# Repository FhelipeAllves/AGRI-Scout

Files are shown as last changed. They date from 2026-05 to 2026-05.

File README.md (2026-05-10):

# AGRI-Scout 🚜
**Autonomous Agricultural Inspection Robot**

AGRI-Scout est un robot agricole différentiel autonome à quatre roues motrices, conçu pour la navigation dans les rangées de cultures et l'analyse de sol in-situ. Il combine la vision par ordinateur, un LiDAR, et une sonde à vis motorisée pour récolter des données pédologiques en temps réel.

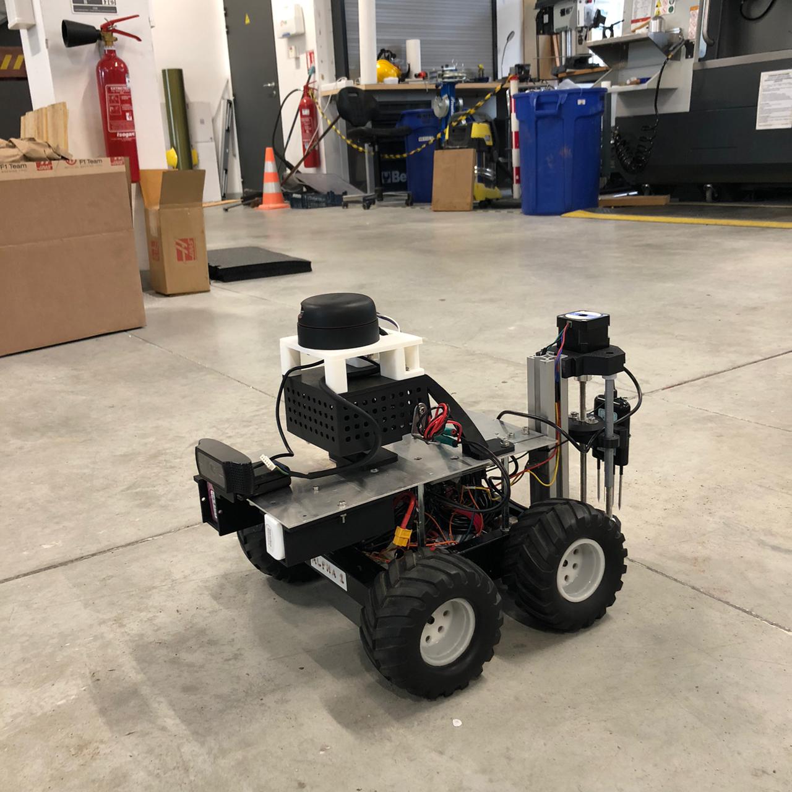
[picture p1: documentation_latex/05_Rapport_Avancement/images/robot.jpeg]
AGRI-Scout


🎥 **[Voir la démo vidéo sur YouTube](https://www.youtube.com/shorts/bMWXOjUjSsw)**

---

## 📑 Sommaire
1. [Caractéristiques Principales](#-caractéristiques-principales)
2. [Architecture Matérielle](#-architecture-matérielle)
3. [Architecture Logicielle](#-architecture-logicielle)
4. [Installation et Prérequis](#-installation-et-prérequis)
5. [Démarrage Rapide](#-démarrage-rapide)
6. [Documentation](#-documentation)
7. [Auteurs](#-auteurs)

---

## 🌟 Caractéristiques Principales

* **Navigation Autonome :** Suivi de ligne blanche au sol via vision par ordinateur (OpenCV) avec contrôleur PD.
* **Évitement d'Obstacles :** Surveillance périmétrique en temps réel grâce au RPLiDAR pour prévenir les collisions.
* **Analyse de Sol Automatisée :** Déploiement mécanique d'une sonde à vis motorisée par un moteur pas-à-pas NEMA 17.
* **Acquisition de Données :** Capteur industriel RS485 (Modbus RTU) mesurant 8 paramètres vitaux : NPK (Azote, Phosphore, Potassium), pH, Température, Humidité, Conductivité Électrique et Salinité.
* **Architecture Distribuée :** Prise de décision par Raspberry Pi 4 (ROS 2 Jazzy) et contrôle bas niveau temps réel par Arduino UNO avec un protocole de communication sécurisé (\textit{watchdog}).

---

## 🛠️ Architecture Matérielle

Le robot est structuré sur deux étages pour isoler physiquement l'électronique de puissance et l'électronique de traitement.

### Composants Clés
* **Calculateur Principal :** Raspberry Pi 4 Model B (4GB)
* **Contrôleur Moteur :** Arduino UNO R3
* **Actionneurs :** 
  * 4x Moteurs DC brushed (Traction, skid-steering)
  * 1x Moteur pas-à-pas NEMA 17 (Sonde)
* **Capteurs :**
  * RPLiDAR (USB)
  * Webcam USB (V4L2)
  * Capteur de sol NPK 8-en-1 (RS485 vers USB)
  * SparkFun OpenLog Artemis (UART)

### Système d'Alimentation
Afin d'éviter les chutes de tension (brown-outs) induites par les appels de courant des moteurs, le système dispose de 3 circuits indépendants :
1. **Batterie LiPo 5000 mAh (3S) :** Moteurs de traction et ESC.
2. **Batterie LiPo 2200 mAh (3S) :** Moteur de la sonde (via Pont en H L298N).
3. **Powerbank USB-C 5V :** Alimentation exclusive du Raspberry Pi.

---

## 💻 Architecture Logicielle

Le projet s'appuie sur le framework **ROS 2 Jazzy** sous Ubuntu 24.04 (ou 22.04 pour versions antérieures compatibles).

* `agri_line_follower.py` : Nœud central intégrant la machine à états finis (FOLLOWING / HARVESTING).
* `agri_demo_hunter.py` : Mode de démonstration pour traquer un objet coloré plutôt qu'une ligne.
* `ros2_teleop.py` : Contrôle manuel du robot via SSH.
* `main_firmware.ino` : Firmware Arduino avec protocole binaire protégé par XOR Checksum et Watchdog matériel.

---

## 🚀 Installation et Prérequis

### Prérequis Logiciels (Raspberry Pi)
* Ubuntu Server/Desktop 24.04
* ROS 2 Jazzy
* Python 3 avec `opencv-python`, `pyserial`, `numpy`

### Clonage et Compilation
```bash
# Cloner le dépôt
git clone https://github.com/VOTRE_UTILISATEUR/AGRI-Scout.git
cd AGRI-Scout/agri-scout-modif

# Sourcer l'environnement ROS 2
source /opt/ros/jazzy/setup.bash

# Compiler l'espace de travail
colcon build --packages-select <nom_des_packages>
```

---

## 🏁 Démarrage Rapide

Pour les instructions détaillées, veuillez consulter le manuel utilisateur (User Manual) dans le dossier de documentation.

1. **Mise sous tension** : 
   - Branchez la Powerbank au Raspberry Pi.
   - Branchez la batterie LiPo 5000mAh et activez l'interrupteur principal.
   - Branchez la batterie LiPo 2200mAh.
2. **Connexion SSH** :
   ```bash
   ssh ubuntu@<IP_DU_RASPBERRY_PI>
   # Mot de passe par défaut : agribot
   ```
3. **Lancement de la Mission Autonome** :
   ```bash
   source /opt/ros/jazzy/setup.bash
   cd ~/AGRI-Scout_Modif
   source install/setup.bash
   ros2 launch ~/AGRI-Scout_Modif/demo.launch.py
   ```

---

## 📚 Documentation

L'intégralité de la documentation technique est disponible au format PDF compilé à partir des sources LaTeX dans `agri-scout-modif/documentation_latex/` :
- **01 Quick Start Guide** : Pour un démarrage immédiat.
- **02 User Manual** : Description détaillée de tous les modes d'utilisation.
- **03 Hardware Maintenance Manual** : Références des pièces, montage, impression 3D et débogage.
- **04 Developer Manual** : Architecture logicielle détaillée et protocole de communication.
- **05 Rapport d'Avancement** : Historique du projet, solutions explorées et perspectives.

---

## 👥 Auteurs

Ce projet a été réalisé par :
* **Pedro Alves**
* **Luiz Felipe**

*Projet réalisé dans le cadre de l'Unité d'Enseignement 3.4 / 4.4 à l'ENSTA Campus de Brest.*

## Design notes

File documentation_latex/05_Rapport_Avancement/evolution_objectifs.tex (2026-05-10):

\section{Objectifs Initiaux et Leur Évolution}

\subsection{Vision Initiale du Projet}

Au démarrage du projet, en septembre 2025, l'équipe avait défini un cahier des charges ambitieux. L'AGRI-Scout devait naviguer de façon autonome entre les rangées de cultures en utilisant la caméra pour suivre les lignes au sol, utiliser YOLO pour la détection et l'évaluation de la récolte (identifier l'état des cultures, détecter des végétaux, fruits ou signes de maladies), s'alimenter via un régulateur de tension centralisé (module Traco Power) depuis une unique batterie LiPo, et déployer une sonde de sol après chaque rangée pour cartographier les données NPK.

Les fonctionnalités de détection de feuilles, fruits, légumes et pestes via YOLO ont été retirées du périmètre du projet en raison des contraintes de temps, de la complexité d'annotation des données et des limitations de puissance de calcul. Ces fonctionnalités sont documentées comme pistes d'amélioration future à la section~\ref{sec:ameliorations}.

\subsection{Les Contraintes Rencontrées}

La confrontation avec la réalité matérielle du projet a révélé plusieurs obstacles imprévus qui ont nécessité des adaptations profondes de l'architecture initiale.

\subsubsection{Instabilité Électrique}

Sous forte charge logicielle, la carte Raspberry Pi 4 seule consomme environ 7W en pointe. Cependant, avec l'activation des périphériques USB (caméra, LiDAR, pont de communication), la consommation globale exigée au système d'alimentation peut facilement atteindre des pics de 12W à 15W.
 Le régulateur Traco Power, partagé avec les ESC des moteurs, ne pouvait pas absorber les pics de courant lors des accélérations, provoquant des chutes de tension et des redémarrages intempestifs (brown-outs) rendant toute mission autonome impossible.

\subsubsection{Problèmes de Communication Série}

Lors des premiers tests, le protocole de communication par caractères ASCII simples s'est avéré fragile : les perturbations électromagnétiques des moteurs corrompaient les trames, et l'accumulation de données dans le tampon série provoquait des blocages rendant le robot incontrôlable.

\subsubsection{Limites Computationnelles pour la Vision}

L'exécution de modèles YOLO sur la Raspberry Pi 4 n'atteignait que 2--3 images par seconde, insuffisant pour un contrôle réactif. Le projet a donc abandonné YOLO pour la phase de navigation, mais cette technologie reste pertinente pour de futures améliorations (voir section~\ref{sec:ameliorations}).

\subsection{Les Pivots Stratégiques}

Face à ces contraintes, l'équipe a procédé à une série d'adaptations qui ont transformé le prototype initial en un système fonctionnel et fiable.

\begin{table}[H]
\centering
\caption{Récapitulatif de l'évolution des objectifs du projet AGRI-Scout.}
\label{tab:evolution}
\renewcommand{\arraystretch}{1.4}
\begin{tabularx}{\textwidth}{|>{\bfseries}p{3.5cm}|X|X|}
\hline
\rowcolor{headerblue!20}
\textbf{Domaine} & \textbf{Objectif Initial} & \textbf{Solution Finale Adoptée} \\
\hline
Alimentation & Régulateur Traco Power centralisé & Isolation galvanique : powerbank USB-C pour la RPi, LiPo principale pour la traction \\
\hline
\rowcolor{rowalt}
Vision (détection récolte) & YOLO pour détecter végétaux, fruits et pestes & Retiré du périmètre ; segmentation HSV colorimétrique pour marqueurs de récolte \\
\hline
Navigation & Planification de trajectoire globale (Nav2) & Navigation réactive par contrôleur PD sur erreur de centrage \\
\hline
\rowcolor{rowalt}
Protocole Série & Trames ASCII simples & Paquets binaires 5 octets avec octet de début/fin et checksum XOR \\
\hline
Architecture logicielle & Scripts Python directs & ROS 2 Jazzy avec noeuds asynchrones et topics dédiés \\
\hline
\end{tabularx}
\end{table}

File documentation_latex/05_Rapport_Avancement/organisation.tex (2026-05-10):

\section{Organisation du Projet}

\subsection{Répartition des Tâches}

Pedro s'est chargé de la partie logicielle : déploiement de ROS 2 Jazzy sur la Raspberry Pi, développement du protocole de communication série sécurisé, calibration de la caméra et des paramètres HSV, et scripts utilitaires (télé-opération, pont série, monitoring). Luiz Felipe a pris en charge la conception physique du robot : modélisation et impression 3D du mécanisme de sondage, des bacs de batteries, de la tourelle LiDAR et des supports de capteurs, ainsi que le câblage électronique complet et le débogage des ESC. Durant la phase finale, les deux membres ont collaboré au développement du noeud principal \texttt{agri\_line\_follower}, aux tests d'intégration en laboratoire, à la campagne de validation terrain et au débogage des problèmes de communication ROS 2.

% ------------------------------------------------------------------ %
%  PHOTOS DU ROBOT - À INSÉRER (décommenter \includegraphics)
% ------------------------------------------------------------------ %
\begin{figure}[H]
    \centering
    
    \caption{Prototype AGRI-Scout finalisé : tourelle LiDAR, mécanisme de sondage et alimentation isolée.}
    \label{fig:robot_final}
\end{figure}

\begin{figure}[H]
    \centering
    \begin{minipage}{0.48\textwidth}
        \centering
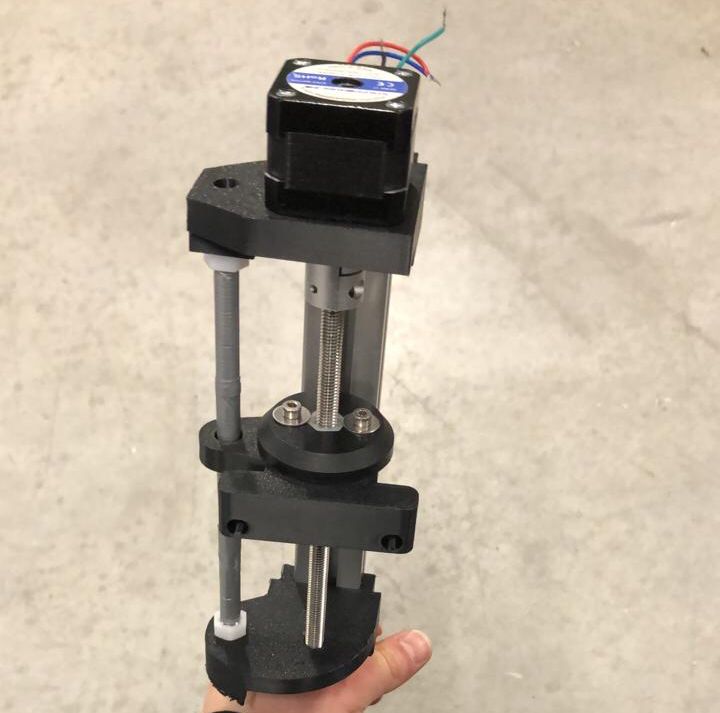
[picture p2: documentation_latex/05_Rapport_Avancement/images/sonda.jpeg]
        
    \end{minipage}
    \hfill
    \begin{minipage}{0.48\textwidth}
        \centering
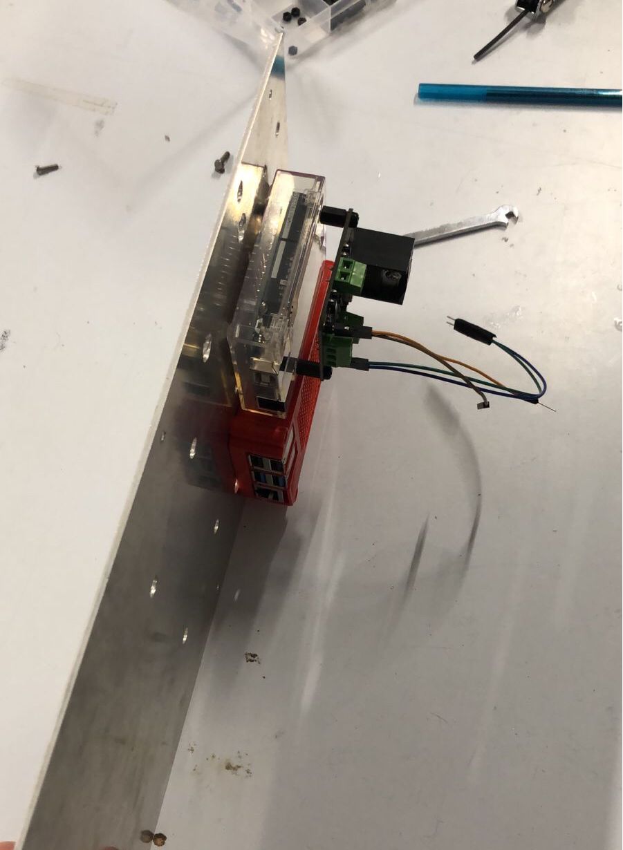
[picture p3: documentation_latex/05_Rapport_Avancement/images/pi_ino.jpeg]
        
    \end{minipage}
    \caption{Gauche : mécanisme de perforation 3D. Droite : architecture électronique avec isolation galvanique.}
    \label{fig:details_robot}
\end{figure}

\subsection{Chronologie du Projet (Septembre 2025 -- Avril 2026)}

Le tableau suivant retrace, mois par mois, les activités qui avaient été planifiées au démarrage du projet.

\renewcommand{\arraystretch}{1.5}
\begin{longtable}{|p{2.8cm}|p{11cm}|}
\hline
\rowcolor{headerblue!20}
\textbf{Mois} & \textbf{Activités Planifiées} \\
\hline
\endfirsthead
\hline
\rowcolor{headerblue!20}
\textbf{Mois} & \textbf{Activités Planifiées} \\
\hline
\endhead
\hline
\multicolumn{2}{r}{\textit{Suite sur la page suivante\ldots}}\\
\endfoot
\hline
\endlastfoot

\textbf{Septembre 2025}
& Définition du cahier des charges, formation de l'équipe, choix de la plateforme matérielle de base. Premiers contacts avec les composants (Arduino, ESC, LiPo). \\
\hline

\rowcolor{rowalt}
\textbf{Octobre 2025}
& Recherche bibliographique et état de l'art. Étude de l'architecture Master-Slave (RPi/Arduino). Premiers tests Arduino (PWM, lecture ultrasons). \\
\hline

\textbf{Novembre 2025}
& Assemblage mécanique préliminaire du châssis. Tests d'alimentation et dimensionnement énergétique. Premiers tests de vision (YOLO sur PC). \\
\hline

\rowcolor{rowalt}
\textbf{Décembre 2025}
& Rédaction du rapport partiel. Validation de la locomotion de base. Identification des problèmes d'alimentation (brown-outs Traco Power). Congés. \\
\hline

\textbf{Janvier 2026}
& Refonte de l'architecture d'alimentation (isolation galvanique). Migration vers USB série. Début de la conception 3D du mécanisme de sondage. Déploiement de ROS 2 Jazzy sur RPi. \\
\hline

\rowcolor{rowalt}
\textbf{Février 2026}
& Développement du noeud ROS 2 \texttt{agri\_line\_follower}. Conception du protocole de communication sécurisé. Impression 3D et assemblage des pièces mécaniques (tourelle LiDAR, bacs batteries). \\
\hline

\textbf{Mars 2026}
& Intégration du LiDAR RPLIDAR. Développement du watchdog logiciel. Tests d'intégration en conditions contrôlées. Calibration de la caméra. Débogage des ESC (frein ABS RC). \\
\hline

\rowcolor{rowalt}
\textbf{Avril 2026}
& Campagne de tests terrain. Validation de la mission autonome complète (suivi de ligne + sondage). Rédaction du rapport final d'avancement. \\
\hline

\end{longtable}

\subsubsection*{Problèmes ayant impacté le planning}

Plusieurs difficultés imprévues ont provoqué des décalages par rapport au planning initial. Le problème d'alimentation a été identifié tardivement et a nécessité une refonte complète de l'architecture électrique, aboutissant à trois sources isolées : une powerbank USB-C pour la Raspberry Pi, une batterie LiPo principale pour la traction, et une seconde batterie LiPo moins puissante dédiée au mécanisme de montée/descente de la sonde. Cette refonte a retardé le démarrage des développements logiciels de plusieurs semaines. La synchronisation entre Python/ROS 2 et le firmware Arduino a également demandé un travail itératif intense. Enfin, une pénurie de filament dans les imprimantes 3D du laboratoire a retardé la fabrication des pièces mécaniques, repoussant les tests finaux et la campagne de validation terrain.

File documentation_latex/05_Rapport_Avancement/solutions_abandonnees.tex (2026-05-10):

\section{Solutions Explorées et Abandonnées}

Cette section documente brièvement les pistes techniques explorées mais finalement écartées. Elle sert de guide aux futurs développeurs pour éviter de répéter les mêmes essais infructueux.

\subsection{Régulateur de Tension Centralisé (Traco Power)}
Le plan initial prévoyait un unique module Traco Power pour alimenter tout le système à partir d'une seule batterie LiPo. En pratique, les pics de courant des moteurs lors des accélérations provoquaient des chutes de tension sur le rail partagé, causant des redémarrages intempestifs de la Raspberry Pi (brown-outs). La solution retenue a été d'isoler électriquement les domaines d'alimentation : la Raspberry Pi est alimentée par une powerbank USB-C indépendante, le système de traction par une batterie LiPo principale, et le mécanisme de montée/descente de la sonde par une seconde batterie LiPo moins puissante, dédiée uniquement à cet actionneur.

\subsection{Vision YOLO pour la Navigation}
L'exécution de modèles YOLO sur la Raspberry Pi 4 n'atteignait que 2--3 images par seconde, insuffisant pour un contrôle réactif. La vision haute résolution a donc été remplacée par une segmentation colorimétrique HSV à 160x120 pixels avec saut de trames, atteignant 10--15 images par seconde. YOLO reste pertinent pour la détection de végétaux et de pestes, mais nécessite un matériel plus puissant (voir section~\ref{sec:ameliorations}).

\subsection{micro-ROS sur Arduino}
La bibliothèque micro-ROS aurait permis d'intégrer l'Arduino directement dans le graphe de communication ROS 2. Cependant, les ressources limitées de l'Arduino Uno (2~Ko de RAM, 32~Ko de Flash) causaient des instabilités mémoire lors de l'exécution simultanée de la sécurité ultrasonique et du client micro-ROS. L'équipe a préféré maintenir un protocole propriétaire léger sur l'Arduino, la logique ROS 2 restant entièrement côté Raspberry Pi.

% \subsection{IMU BNO055}
% L'IMU BNO055 avait été envisagée pour corriger les dérives de trajectoire dues au glissement (skid-steering). En pratique, le champ magnétique des moteurs perturbait la boussole interne, rendant les données de cap peu fiables. L'odométrie visuelle par centroïde de ligne, couplée au LiDAR, a suffi pour les missions de suivi de rang.

\subsection{Navigation Globale avec Nav2}
La stack Nav2 de ROS 2, qui inclut des planificateurs de trajectoire de type A*, a été étudiée. Son intégration exige une carte de l'environnement (via SLAM) et un système de localisation robuste, deux éléments non disponibles dans le périmètre du projet. Le contrôleur PD réactif, bien que plus simple, a été suffisant pour les missions en rang droit.

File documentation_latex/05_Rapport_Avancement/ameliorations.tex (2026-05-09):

\section{Pistes d'Amélioration et Perspectives Futures}
\label{sec:ameliorations}

Cette section s'adresse aux futurs développeurs du projet AGRI-Scout. Les axes proposés sont classés par ordre croissant de difficulté et de complexité. Le choix du matériel et des bibliothèques devra être adapté au budget et aux équipements disponibles à l'ENSTA au moment de la reprise du projet.

% ----------------------------------------------------------
\subsection{Axe 1 : Refonte Mécanique et Châssis}

Le point de départ le plus accessible pour les prochains groupes est une intervention purement mécanique, sans modifier le logiciel existant. Le châssis de base actuel est un châssis RC générique dont les moteurs posent des problèmes récurrents de décalibration : la symétrie de puissance entre les roues gauche et droite se dégrade au fil du temps, rendant le suivi de ligne de moins en moins précis.

L'objectif de cet axe serait de remodeler le châssis de base et l'ensemble du système de roues pour obtenir un robot visuellement plus propre, mieux organisé et plus fiable mécaniquement. Un système de propulsion plus tolérant aux défaillances — par exemple des moteurs à encodeurs qui permettent un retour de position réel — résoudrait directement le problème de décalibration. Cette refonte permettrait aux étudiants de travailler sur différentes pièces mécaniques et matériaux, de concevoir et imprimer de nouvelles pièces en 3D, et, une fois la mécanique stabilisée, de garantir un fonctionnement optimal des algorithmes de navigation déjà existants sans toucher au code.

\noindent Compétences développées : CAO (Autodesk Inventor / Fusion 360), impression 3D, intégration mécanique-électronique, caractérisation de moteurs DC.

\noindent Ressources utiles :
\begin{itemize}
    \item Encodeurs et moteurs DC à encodeur (exemple : Pololu) : \url{https://www.pololu.com/category/12/motors-solenoids-driver-boards}
    \item Modeles 3D pour la robotique : \url{https://grabcad.com/library?categories=robotics}
    \item Comparatif châssis robotiques : \href{https://www.fdatabot.com/top-10-mobile-robot-chassis-compared-types-features-selection-guide/}{Lien vers fdatabot.com}
\end{itemize}

% ----------------------------------------------------------
\subsection{Axe 2 : Upgrade Matériel et Navigation Avancée}

La principale limitation de l'architecture actuelle est la puissance de calcul de la Raspberry Pi 4, insuffisante pour des algorithmes de vision ou de planification complexes. Remplacer l'ordinateur de bord par une plateforme plus puissante, comme une NVIDIA Jetson ou un Arduino UNO Q 4GB (carte Arduino intégrant processeur et capacités d'IA dans un module compact, alternative économique à environ 60~€), permettrait d'envisager l'intégration de Nav2 \cite{ros2_nav2} avec un algorithme A* pour la navigation autonome en champ.

\noindent Ressources utiles :
\begin{itemize}
    \item NVIDIA Jetson --- portail développeur : \url{https://developer.nvidia.com/embedded/develop/hardware}
    \item Arduino UNO Q --- page officielle Arduino : \url{https://www.arduino.cc/product-uno-q}
    \item Navigation 2 (Nav2) --- documentation ROS 2 : \url{https://docs.nav2.org/index.html}
    \item Algorithme A* expliqué visuellement : \url{https://www.redblobgames.com/pathfinding/a-star/introduction.html}
\end{itemize}

% ----------------------------------------------------------
\subsection{Axe 3 : Détection de Végétation et de Pestes par YOLO}

Cet axe reprend l'objectif initial du projet, retiré du périmètre par contrainte de temps et de calcul : utiliser un modèle YOLO entraîné sur des images agricoles pour identifier l'état des cultures (plantes malades, stress hydrique, infestations), détecter des fruits mûrs ou légumes prêts à la récolte, et classifier le type de culture pour adapter les seuils d'analyse NPK. Des bases de données annotées existent librement en ligne pour entraîner ou affiner le modèle.

\noindent Ressources utiles :
\begin{itemize}
    \item Documentation officielle Ultralytics YOLO : \url{https://docs.ultralytics.com/}
    \item Dataset PlantVillage (maladies de plantes) : \url{https://www.kaggle.com/datasets/emmarex/plantdisease}
    \item Datasets agricoles annotés (Roboflow Universe) : \url{https://universe.roboflow.com/search?q=pest+detection+agriculture}
    \item Tutoriel entraînement YOLO sur dataset personnalisé : \url{https://docs.ultralytics.com/modes/train/}
\end{itemize}

% ----------------------------------------------------------
\subsection{Axe 4 : Navigation GPS RTK et Missions par Points de Passage}

L'intégration d'un récepteur GPS RTK représente l'axe le plus ambitieux et le plus complexe techniquement, mais aussi le plus coûteux en termes d'équipement. Un GPS RTK permettrait une localisation absolue de précision décimétrique à centimétrique, ouvrant la voie à des missions géoréférencées par waypoints : l'opérateur définirait à l'avance les positions d'échantillonnage sur une carte et le robot naviguerait automatiquement entre ces points, générant une carte de fertilité géoréférencée de la parcelle.

La principale contrainte de cet axe est le coût du matériel : un récepteur GPS RTK de qualité professionnelle représente un investissement significatif qui dépasse généralement le budget d'un projet étudiant. Cependant, une précision de l'ordre du mètre (voire inférieure) serait déjà suffisante pour réaliser des missions agricoles intéressantes et des études approfondies. La faisabilité de cet axe dépendra donc directement de la disponibilité d'un équipement compatible au sein de l'ENSTA ou d'un prêt institutionnel.

Sur le plan logiciel, un filtre de Kalman étendu, disponible via le package ROS 2 \texttt{robot\_localization}, permettrait de fusionner les données GPS, IMU et odométrie pour une localisation robuste en conditions réelles.

\noindent Ressources utiles :
\begin{itemize}
    \item Package ROS 2 \texttt{robot\_localization} (EKF) : \url{https://docs.ros.org/en/noetic/api/robot_localization/html/index.html}
    \item Introduction au filtre de Kalman --- tutoriel visuel : \url{https://www.bzarg.com/p/how-a-kalman-filter-works-in-pictures/}
    \item Guide GPS RTK open-source (ZED-F9P, $\sim$200~€) : \url{https://learn.sparkfun.com/tutorials/gps-rtk2-hookup-guide}
\end{itemize}

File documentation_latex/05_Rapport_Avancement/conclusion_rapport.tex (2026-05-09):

\section{Conclusion}

Le projet AGRI-Scout aura été, avant tout, une leçon sur la distance qui sépare la conception théorique de la réalité du déploiement matériel. Les obstacles rencontrés (instabilité électrique, synchronisation Python/Arduino, contraintes d'impression 3D, limitations de calcul pour la vision) ont conduit l'équipe à repenser ses choix de façon itérative, aboutissant souvent à des solutions plus simples mais plus robustes que celles envisagées initialement. Le prototype final remplit ses objectifs fondamentaux : navigation autonome par suivi de ligne, détection d'obstacles par LiDAR, mécanisme de sondage du sol conçu et fabriqué en 3D, et collecte automatisée de données multiparamétriques via la sonde industrielle RS485.

Ce projet a permis à l'équipe d'acquérir une expérience pratique dans des domaines rarement enseignés en cours magistral : gestion des conflits électroniques en système embarqué, conception mécanique itérative, débogage de systèmes distribués en temps réel. La valeur de ce travail ne réside pas uniquement dans le robot livré, mais aussi dans la documentation des impasses techniques. Savoir ce qui n'a pas fonctionné est essentiel. Les solutions abandonnées et les pivots stratégiques constituent, pour les futurs développeurs, un guide pour éviter de répéter les mêmes erreurs et accélérer la prise en main du système.

L'AGRI-Scout est un prototype qui peut encore progresser. La réintégration de la détection YOLO pour la reconnaissance des végétaux et des pestes, la navigation par waypoints GPS RTK, et l'utilisation d'une plateforme de calcul plus puissante sont des pistes concrètes pour les prochaines équipes qui reprendront ce projet.

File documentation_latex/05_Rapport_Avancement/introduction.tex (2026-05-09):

\section{Introduction}

\subsection{Contexte et Motivation}

Face à la croissance démographique mondiale et à la nécessité de préserver les ressources environnementales, l'agriculture moderne opère une transition vers l'agriculture de précision. Cette approche vise à optimiser les rendements tout en minimisant l'usage d'intrants grâce à une gestion différenciée des parcelles \cite{precision_ag_review}.

La qualité du sol est un facteur déterminant pour la santé des cultures. Traditionnellement, son analyse nécessite un échantillonnage manuel fastidieux et des analyses en laboratoire coûteuses, ce qui limite la fréquence des données disponibles pour l'agriculteur \cite{soil_sensing_review}. L'automatisation de ce processus par la robotique mobile constitue une solution pour permettre un suivi temporel et spatial plus régulier \cite{agri_robotics}.

\subsection{Présentation du Projet AGRI-Scout}

Le projet AGRI-Scout vise à concevoir et prototyper un robot mobile autonome capable de naviguer dans des rangées de cultures et d'effectuer des inspections in-situ. Le système intègre une plateforme de locomotion différentielle (skid-steering) pilotée par des ESC et supervisée par un Arduino Uno, une Raspberry Pi 4 exécutant ROS 2 Jazzy pour la navigation par vision et l'intégration LiDAR, et une sonde multiparamétrique 8-en-1 (NPK, pH, humidité, température, conductivité électrique) déployée via un mécanisme de perforation conçu et imprimé en 3D.

\subsection{Périmètre de ce Rapport}

Ce rapport d'avancement final n'est pas un document technique architectural. Son objectif est de retracer l'évolution du projet depuis ses ambitions initiales jusqu'à la version livrée : les adaptations imposées par les contraintes du terrain, l'organisation de l'équipe, les solutions explorées qui n'ont pas été retenues, et les pistes d'amélioration pour les futurs développeurs.

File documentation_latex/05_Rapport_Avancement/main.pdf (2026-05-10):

# (UE 4.4 - Projet)

### Agri-Scout : Robot Autonome pour l’Inspection Agricole et l’Analyse des Sols

# Rapport d’avancement interne

ENSTA Campus de Brest
2 Rue François Verny
29200 Brest Cedex 9, France Pedro ALVES DE ARAUJO SILVA pedro.alves@ensta.fr
Luiz Felipe BARROS ALVES
luiz.barros@ensta.fr

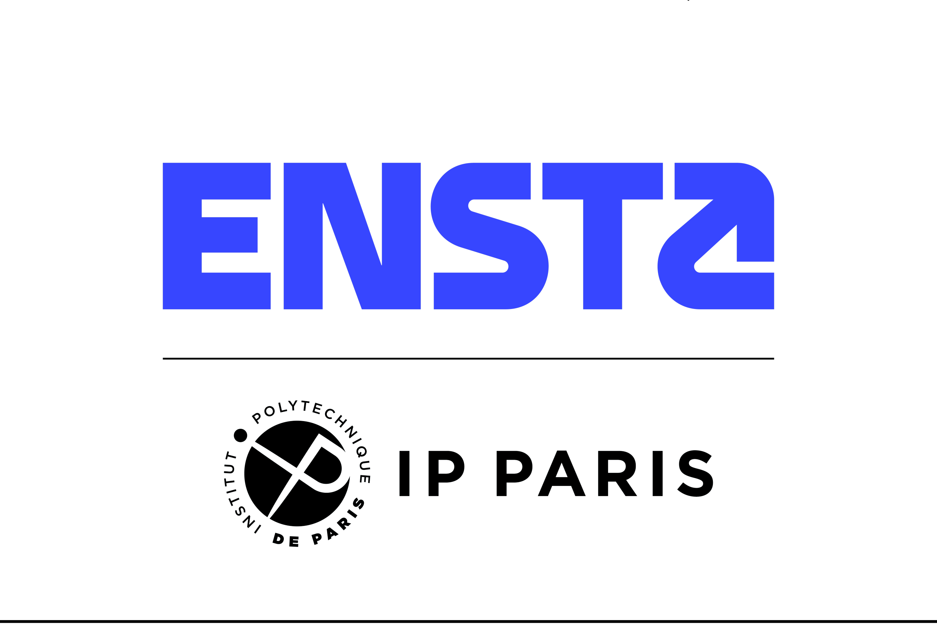
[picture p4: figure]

## Sommaire

1 Introduction | 1
2 Objectifs Initiaux et Leur Évolution | 1
3 Organisation du Projet | 3
4 Solutions Explorées et Abandonnées | 6

5 Pistes d’Amélioration et Perspectives Futures | 7
5.4 Axe 4 : Navigation GPS RTK et Missions par Points de Passage . . . | 8
6 Conclusion | 9

UE 4.4 - Projet | 1

## 1 Introduction

### 1.1 Contexte et Motivation

Face à la croissance démographique mondiale et à la nécessité de préserver les ressources environnementales, l’agriculture moderne opère une transition vers l’agriculture de précision. Cette approche vise à optimiser les rendements tout en minimisant l’usage d’intrants grâce à une gestion différenciée des parcelles [1].
La qualité du sol est un facteur déterminant pour la santé des cultures. Traditionnellement, son analyse nécessite un échantillonnage manuel fastidieux et des analyses en laboratoire coûteuses, ce qui limite la fréquence des données disponibles pour l’agriculteur [2]. L’automatisation de ce processus par la robotique mobile constitue une solution pour permettre un suivi temporel et spatial plus régulier [3].

### 1.2 Présentation du Projet AGRI-Scout

Le projet AGRI-Scout vise à concevoir et prototyper un robot mobile autonome capable de naviguer dans des rangées de cultures et d’effectuer des inspections insitu. Le système intègre une plateforme de locomotion différentielle (skid-steering) pilotée par des ESC et supervisée par un Arduino Uno, une Raspberry Pi 4 exécutant ROS 2 Jazzy pour la navigation par vision et l’intégration LiDAR, et une sonde multiparamétrique 8-en-1 (NPK, pH, humidité, température, conductivité électrique) déployée via un mécanisme de perforation conçu et imprimé en 3D.

### 1.3 Périmètre de ce Rapport

Ce rapport d’avancement final n’est pas un document technique architectural. Son objectif est de retracer l’évolution du projet depuis ses ambitions initiales jusqu’à la version livrée : les adaptations imposées par les contraintes du terrain, l’organisation de l’équipe, les solutions explorées qui n’ont pas été retenues, et les pistes d’amélioration pour les futurs développeurs.

## 2 Objectifs Initiaux et Leur Évolution

### 2.1 Vision Initiale du Projet

Au démarrage du projet, en septembre 2025, l’équipe avait défini un cahier des charges ambitieux. L’AGRI-Scout devait naviguer de façon autonome entre les rangées de cultures en utilisant la caméra pour suivre les lignes au sol, utiliser YOLO pour la détection et l’évaluation de la récolte (identifier l’état des cultures, détecter des végétaux, fruits ou signes de maladies), s’alimenter via un régulateur de tension centralisé (module Traco Power) depuis une unique batterie LiPo, et déployer une sonde de sol après chaque rangée pour cartographier les données NPK.
Les fonctionnalités de détection de feuilles, fruits, légumes et pestes via YOLO ont été retirées du périmètre du projet en raison des contraintes de temps, de la complexité d’annotation des données et des limitations de puissance de calcul. Ces fonctionnalités sont documentées comme pistes d’amélioration future à la section 5.

### 2.2 Les Contraintes Rencontrées

La confrontation avec la réalité matérielle du projet a révélé plusieurs obstacles imprévus qui ont nécessité des adaptations profondes de l’architecture initiale.

### 2.2.1 Instabilité Électrique

Sous forte charge logicielle, la carte Raspberry Pi 4 seule consomme environ 7W en pointe. Cependant, avec l’activation des périphériques USB (caméra, LiDAR, pont de communication), la consommation globale exigée au système d’alimentation peut facilement atteindre des pics de 12W à 15W. Le régulateur Traco Power, partagé avec les ESC des moteurs, ne pouvait pas absorber les pics de courant lors des accélérations, provoquant des chutes de tension et des redémarrages intempestifs (brown-outs) rendant toute mission autonome impossible.

### 2.2.2 Problèmes de Communication Série

Lors des premiers tests, le protocole de communication par caractères ASCII simples s’est avéré fragile : les perturbations électromagnétiques des moteurs corrompaient les trames, et l’accumulation de données dans le tampon série provoquait des blocages rendant le robot incontrôlable.

### 2.2.3 Limites Computationnelles pour la Vision

L’exécution de modèles YOLO sur la Raspberry Pi 4 n’atteignait que 2–3 images par seconde, insuffisant pour un contrôle réactif. Le projet a donc abandonné YOLO pour la phase de navigation, mais cette technologie reste pertinente pour de futures améliorations (voir section 5).

### 2.3 Les Pivots Stratégiques

Face à ces contraintes, l’équipe a procédé à une série d’adaptations qui ont transformé le prototype initial en un système fonctionnel et fiable.

Table 1 – Récapitulatif de l’évolution des objectifs du projet AGRI-Scout.

Domaine | Objectif Initial | Solution Finale Adoptée
Alimentation | Régulateur Traco Power centralisé | Isolation galvanique : power-bank USB-C pour la RPi, LiPo principale pour la trac-tion
Vision (détec-tion récolte) | YOLO pour détecter végé-taux, fruits et pestes | Retiré du périmètre ; seg-mentation HSV colorimé-trique pour marqueurs de ré-colte
Navigation | Planification de trajectoire globale (Nav2) | Navigation réactive par contrôleur PD sur erreur de centrage
Protocole Série | Trames ASCII simples | Paquets binaires 5 octets avec octet de début/fin et checksum XOR
Architecture lo-gicielle | Scripts Python directs | ROS 2 Jazzy avec noeuds asynchrones et topics dédiés

## 3 Organisation du Projet

### 3.1 Répartition des Tâches

Pedro s’est chargé de la partie logicielle : déploiement de ROS 2 Jazzy sur la Raspberry Pi, développement du protocole de communication série sécurisé, calibration de la caméra et des paramètres HSV, et scripts utilitaires (télé-opération, pont série, monitoring). Luiz Felipe a pris en charge la conception physique du robot : modélisation et impression 3D du mécanisme de sondage, des bacs de batteries, de la tourelle LiDAR et des supports de capteurs, ainsi que le câblage électronique complet et le débogage des ESC. Durant la phase finale, les deux membres ont collaboré au développement du noeud principal agri_line_follower, aux tests d’intégration en laboratoire, à la campagne de validation terrain et au débogage des problèmes de communication ROS 2.

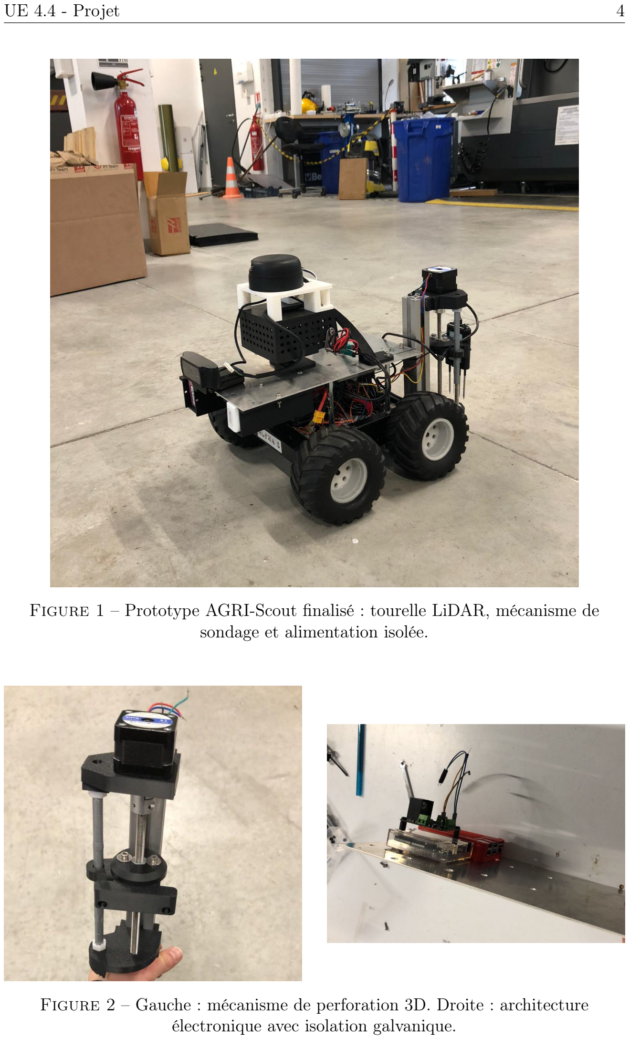
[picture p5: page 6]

Figure 1 – Prototype AGRI-Scout finalisé : tourelle LiDAR, mécanisme de sondage et alimentation isolée.

Figure 2 – Gauche : mécanisme de perforation 3D. Droite : architecture électronique avec isolation galvanique.

### 3.2 Chronologie du Projet (Septembre 2025 – Avril 2026)

Le tableau suivant retrace, mois par mois, les activités qui avaient été planifiées au démarrage du projet.

Mois | Activités Planifiées
Septembre 2025 | Définition du cahier des charges, formation de l’équipe, choix de la plateforme matérielle de base. Premiers contacts avec les composants (Arduino, ESC, LiPo).
Octobre 2025 | Recherche bibliographique et état de l’art. Étude de l’archi-tecture Master-Slave (RPi/Arduino). Premiers tests Arduino (PWM, lecture ultrasons).
Novembre 2025 | Assemblage mécanique préliminaire du châssis. Tests d’ali-mentation et dimensionnement énergétique. Premiers tests de vision (YOLO sur PC).
Décembre 2025 | Rédaction du rapport partiel. Validation de la locomotion de base. Identification des problèmes d’alimentation (brown-outs Traco Power). Congés.
Janvier 2026 | Refonte de l’architecture d’alimentation (isolation galva-nique). Migration vers USB série. Début de la conception 3D du mécanisme de sondage. Déploiement de ROS 2 Jazzy sur RPi.
Février 2026 | Développement du noeud ROS 2 agri_line_follower. Conception du protocole de communication sécurisé. Impres-sion 3D et assemblage des pièces mécaniques (tourelle LiDAR, bacs batteries).
Mars 2026 | Intégration du LiDAR RPLIDAR. Développement du watch-dog logiciel. Tests d’intégration en conditions contrôlées. Ca-libration de la caméra. Débogage des ESC (frein ABS RC).
Avril 2026 | Campagne de tests terrain. Validation de la mission autonome complète (suivi de ligne + sondage). Rédaction du rapport final d’avancement.

Problèmes ayant impacté le planning

Plusieurs difficultés imprévues ont provoqué des décalages par rapport au planning initial. Le problème d’alimentation a été identifié tardivement et a nécessité une refonte complète de l’architecture électrique, aboutissant à trois sources isolées : une powerbank USB-C pour la Raspberry Pi, une batterie LiPo principale pour la traction, et une seconde batterie LiPo moins puissante dédiée au mécanisme de montée/descente de la sonde. Cette refonte a retardé le démarrage des développements logiciels de plusieurs semaines. La synchronisation entre Python/ROS 2 et le firmware Arduino a également demandé un travail itératif intense. Enfin, une pénurie de filament dans les imprimantes 3D du laboratoire a retardé la fabrication des pièces mécaniques, repoussant les tests finaux et la campagne de validation terrain.

## 4 Solutions Explorées et Abandonnées

Cette section documente brièvement les pistes techniques explorées mais finalement écartées. Elle sert de guide aux futurs développeurs pour éviter de répéter les mêmes essais infructueux.

### 4.1 Régulateur de Tension Centralisé (Traco Power)

Le plan initial prévoyait un unique module Traco Power pour alimenter tout le système à partir d’une seule batterie LiPo. En pratique, les pics de courant des moteurs lors des accélérations provoquaient des chutes de tension sur le rail partagé, causant des redémarrages intempestifs de la Raspberry Pi (brown-outs). La solution retenue a été d’isoler électriquement les domaines d’alimentation : la Raspberry Pi est alimentée par une powerbank USB-C indépendante, le système de traction par une batterie LiPo principale, et le mécanisme de montée/descente de la sonde par une seconde batterie LiPo moins puissante, dédiée uniquement à cet actionneur.

### 4.2 Vision YOLO pour la Navigation

L’exécution de modèles YOLO sur la Raspberry Pi 4 n’atteignait que 2–3 images par seconde, insuffisant pour un contrôle réactif. La vision haute résolution a donc été remplacée par une segmentation colorimétrique HSV à 160x120 pixels avec saut de trames, atteignant 10–15 images par seconde. YOLO reste pertinent pour la détection de végétaux et de pestes, mais nécessite un matériel plus puissant (voir section 5).

### 4.3 micro-ROS sur Arduino

La bibliothèque micro-ROS aurait permis d’intégrer l’Arduino directement dans le graphe de communication ROS 2. Cependant, les ressources limitées de l’Arduino Uno (2 Ko de RAM, 32 Ko de Flash) causaient des instabilités mémoire lors de l’exécution simultanée de la sécurité ultrasonique et du client micro-ROS. L’équipe a préféré maintenir un protocole propriétaire léger sur l’Arduino, la logique ROS 2 restant entièrement côté Raspberry Pi.

### 4.4 Navigation Globale avec Nav2

La stack Nav2 de ROS 2, qui inclut des planificateurs de trajectoire de type A*, a été étudiée. Son intégration exige une carte de l’environnement (via SLAM) et un système de localisation robuste, deux éléments non disponibles dans le périmètre du projet. Le contrôleur PD réactif, bien que plus simple, a été suffisant pour les missions en rang droit.

## 5 Pistes d’Amélioration et Perspectives Futures

Cette section s’adresse aux futurs développeurs du projet AGRI-Scout. Les axes proposés sont classés par ordre croissant de difficulté et de complexité. Le choix du matériel et des bibliothèques devra être adapté au budget et aux équipements disponibles à l’ENSTA au moment de la reprise du projet.

### 5.1 Axe 1 : Refonte Mécanique et Châssis

Le point de départ le plus accessible pour les prochains groupes est une intervention purement mécanique, sans modifier le logiciel existant. Le châssis de base actuel est un châssis RC générique dont les moteurs posent des problèmes récurrents de décalibration : la symétrie de puissance entre les roues gauche et droite se dégrade au fil du temps, rendant le suivi de ligne de moins en moins précis.
L’objectif de cet axe serait de remodeler le châssis de base et l’ensemble du système de roues pour obtenir un robot visuellement plus propre, mieux organisé et plus fiable mécaniquement. Un système de propulsion plus tolérant aux défaillances — par exemple des moteurs à encodeurs qui permettent un retour de position réel — résoudrait directement le problème de décalibration. Cette refonte permettrait aux étudiants de travailler sur différentes pièces mécaniques et matériaux, de concevoir et imprimer de nouvelles pièces en 3D, et, une fois la mécanique stabilisée, de garantir un fonctionnement optimal des algorithmes de navigation déjà existants sans toucher au code.
Compétences développées : CAO (Autodesk Inventor / Fusion 360), impression 3D, intégration mécanique-électronique, caractérisation de moteurs DC.
Ressources utiles :
— Encodeurs et moteurs DC à encodeur (exemple : Pololu) : https://www.pololu.com/category/12/motors-solenoids-driver-boards
— Modeles 3D pour la robotique : https://grabcad.com/library?categories=robotics (https://grabcad.com/library?categories=robotics)
— Comparatif châssis robotiques : Lien vers fdatabot.com (https://www.fdatabot.com/top-10-mobile-robot-chassis-compared-types-features-selection-guide/)

### 5.2 Axe 2 : Upgrade Matériel et Navigation Avancée

La principale limitation de l’architecture actuelle est la puissance de calcul de la Raspberry Pi 4, insuffisante pour des algorithmes de vision ou de planification complexes. Remplacer l’ordinateur de bord par une plateforme plus puissante, comme une NVIDIA Jetson ou un Arduino UNO Q 4GB (carte Arduino intégrant processeur et capacités d’IA dans un module compact, alternative économique à environ 60 €), permettrait d’envisager l’intégration de Nav2 [4] avec un algorithme A* pour la navigation autonome en champ.
Ressources utiles :
— NVIDIA Jetson — portail développeur : https://developer.nvidia.com/embedded/develop/hardware (https://developer.nvidia.com/embedded/develop/hardware)
— Arduino UNO Q — page officielle Arduino : https://www.arduino.cc/product-uno-q (https://www.arduino.cc/product-uno-q)

— Navigation 2 (Nav2) — documentation ROS 2 : https://docs.nav2.org/index.html (https://docs.nav2.org/index.html)
— Algorithme A* expliqué visuellement : https://www.redblobgames.com/pathfinding/a-star/introduction.html (https://www.redblobgames.com/pathfinding/a-star/introduction.html)

### 5.3 Axe 3 : Détection de Végétation et de Pestes par YOLO

Cet axe reprend l’objectif initial du projet, retiré du périmètre par contrainte de temps et de calcul : utiliser un modèle YOLO entraîné sur des images agricoles pour identifier l’état des cultures (plantes malades, stress hydrique, infestations), détecter des fruits mûrs ou légumes prêts à la récolte, et classifier le type de culture pour adapter les seuils d’analyse NPK. Des bases de données annotées existent librement en ligne pour entraîner ou affiner le modèle.
Ressources utiles :
— Documentation officielle Ultralytics YOLO : https://docs.ultralytics.com/ (https://docs.ultralytics.com/)
— Dataset PlantVillage (maladies de plantes) : https://www.kaggle.com/datasets/emmarex/plantdisease (https://www.kaggle.com/datasets/emmarex/plantdisease)
— Datasets agricoles annotés (Roboflow Universe) : https://universe.roboflow.com/search?q=pest+detection+agriculture (https://universe.roboflow.com/search?q=pest+detection+agriculture)
— Tutoriel entraînement YOLO sur dataset personnalisé : https://docs.ultralytics.com/modes/train/ (https://docs.ultralytics.com/modes/train/)

### 5.4 Axe 4 : Navigation GPS RTK et Missions par Points de

Passage

L’intégration d’un récepteur GPS RTK représente l’axe le plus ambitieux et le plus complexe techniquement, mais aussi le plus coûteux en termes d’équipement. Un GPS RTK permettrait une localisation absolue de précision décimétrique à centimétrique, ouvrant la voie à des missions géoréférencées par waypoints : l’opérateur définirait à l’avance les positions d’échantillonnage sur une carte et le robot naviguerait automatiquement entre ces points, générant une carte de fertilité géoréférencée de la parcelle.
La principale contrainte de cet axe est le coût du matériel : un récepteur GPS RTK de qualité professionnelle représente un investissement significatif qui dépasse généralement le budget d’un projet étudiant. Cependant, une précision de l’ordre du mètre (voire inférieure) serait déjà suffisante pour réaliser des missions agricoles intéressantes et des études approfondies. La faisabilité de cet axe dépendra donc directement de la disponibilité d’un équipement compatible au sein de l’ENSTA ou d’un prêt institutionnel.
Sur le plan logiciel, un filtre de Kalman étendu, disponible via le package ROS 2 robot_localization, permettrait de fusionner les données GPS, IMU et odométrie pour une localisation robuste en conditions réelles.
Ressources utiles :
— Package ROS 2 robot_localization (EKF) : https://docs.ros.org/en/noetic/api/robot_localization/html/index.html (https://docs.ros.org/en/noetic/api/robot_localization/html/index.html)

— Introduction au filtre de Kalman — tutoriel visuel : https://www.bzarg.com/p/how-a-kalman-filter-works-in-pictures/ (https://www.bzarg.com/p/how-a-kalman-filter-works-in-pictures/)
— Guide GPS RTK open-source (ZED-F9P, ∼200 €) : https://learn.sparkfun.com/tutorials/gps-rtk2-hookup-guide (https://learn.sparkfun.com/tutorials/gps-rtk2-hookup-guide)

## 6 Conclusion

Le projet AGRI-Scout aura été, avant tout, une leçon sur la distance qui sépare la conception théorique de la réalité du déploiement matériel. Les obstacles rencontrés (instabilité électrique, synchronisation Python/Arduino, contraintes d’impression 3D, limitations de calcul pour la vision) ont conduit l’équipe à repenser ses choix de façon itérative, aboutissant souvent à des solutions plus simples mais plus robustes que celles envisagées initialement. Le prototype final remplit ses objectifs fondamentaux : navigation autonome par suivi de ligne, détection d’obstacles par Li-DAR, mécanisme de sondage du sol conçu et fabriqué en 3D, et collecte automatisée de données multiparamétriques via la sonde industrielle RS485.
Ce projet a permis à l’équipe d’acquérir une expérience pratique dans des domaines rarement enseignés en cours magistral : gestion des conflits électroniques en système embarqué, conception mécanique itérative, débogage de systèmes distribués en temps réel. La valeur de ce travail ne réside pas uniquement dans le robot livré, mais aussi dans la documentation des impasses techniques. Savoir ce qui n’a pas fonctionné est essentiel. Les solutions abandonnées et les pivots stratégiques constituent, pour les futurs développeurs, un guide pour éviter de répéter les mêmes erreurs et accélérer la prise en main du système.
L’AGRI-Scout est un prototype qui peut encore progresser. La réintégration de la détection YOLO pour la reconnaissance des végétaux et des pestes, la navigation par waypoints GPS RTK, et l’utilisation d’une plateforme de calcul plus puissante sont des pistes concrètes pour les prochaines équipes qui reprendront ce projet.

## Références

[1] Emogine Mamabolo et al., Application of precision agriculture technologies for crop protection and soil health, https://www.sciencedirect.com/science/article/pii/S2772375525005015 (https://www.sciencedirect.com/science/article/pii/S2772375525005015)
[2] Raphael A. Viscarra Rossel and Johan Bouma, Soil sensing : A new paradigm for agriculture, https://www.sciencedirect.com/science/article/pii/S0308521X16303110 (https://www.sciencedirect.com/science/article/pii/S0308521X16303110)
[3] Tom Duckett et al., Agricultural Robotics : The Future of Robotic
Agriculture, | https://research.manchester.ac.uk/en/publications/
agricultural-robotics-the-future-of-robotic-agriculture/ (https://research.manchester.ac.uk/en/publications/agricultural-robotics-the-future-of-robotic-agriculture/)
[4] Open Robotics, Navigation 2 — ROS 2 Navigation Framework, https://navigation.ros.org/
[5] SparkFun Electronics, ZED-F9P GPS-RTK2 Board Hookup Guide, https://learn.sparkfun.com/tutorials/gps-rtk2-hookup-guide

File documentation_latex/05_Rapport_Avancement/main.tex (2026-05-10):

\documentclass [12pt, a4paper]{article}

% Acentos e Francês
\usepackage[utf8]{inputenc}
\usepackage[french]{babel}
\usepackage{wrapfig}
\usepackage[pdftex]{color,graphicx}
\usepackage{mathrsfs}
\usepackage[labelformat = empty]{subcaption}
\usepackage[justification=centering]{caption}
\usepackage[]{multirow}
\usepackage{float}
\usepackage{longtable}
\usepackage{tabularx}
\usepackage{booktabs}
\usepackage{array}
\usepackage[usenames,dvipsnames,svgnames,table]{xcolor}
\usepackage{siunitx}
\usepackage{upquote}
\usepackage{amsmath}
\usepackage{hyperref}
\usepackage{tikz}
\usetikzlibrary{patterns}
\usepackage{listings}
\usepackage{pdflscape}
\usepackage{setspace}
\usepackage{indentfirst}
\usepackage{multicol}

% Couleurs
\definecolor{meu}{RGB}{0,102,161}
\definecolor{codegreen}{rgb}{0,0.6,0}
\definecolor{codegray}{rgb}{0.5,0.5,0.5}
\definecolor{codepurple}{rgb}{0.58,0,0.82}
\definecolor{backcolour}{rgb}{0.95,0.95,0.92}
\definecolor{rowalt}{RGB}{240,248,255}
\definecolor{headerblue}{RGB}{0,102,161}

\lstdefinestyle{mystyle}{
    backgroundcolor=\color{backcolour},
    commentstyle=\color{codegreen},
    keywordstyle=\color{magenta},
    numberstyle=\tiny\color{codegray},
    stringstyle=\color{codepurple},
    basicstyle=\ttfamily\footnotesize,
    breaklines=true,
    captionpos=b,
    keepspaces=true,
    numbers=left,
    numbersep=5pt,
    showspaces=false,
    tabsize=2
}
\lstset{style=mystyle}

% Margens
\usepackage[top=3cm, bottom=3cm, left=3cm, right=3cm]{geometry}
\usepackage[T1]{fontenc}

\usepackage{fancyhdr}
\setlength{\headheight}{14.5pt}
\addtolength{\topmargin}{-2.5pt}
\pagestyle{fancy}
\fancyhf{}
\lhead{UE 4.4 - Projet \hfill \thepage}

\begin{document}

% Capa de apresentação
\input{Capa}

% Sommaire
\renewcommand{\contentsname}{\centering Sommaire}
\tableofcontents
\thispagestyle{empty}
\setcounter{page}{0}

\newpage
\input{introduction}
\input{evolution_objectifs}
\input{organisation}
\input{solutions_abandonnees}
\input{ameliorations}
\input{conclusion_rapport}

\newpage
\begin{thebibliography}{9}

\bibitem{precision_ag_review}
  Emogine Mamabolo et al., \emph{Application of precision agriculture technologies for crop protection and soil health},
  \url{https://www.sciencedirect.com/science/article/pii/S2772375525005015}

\bibitem{soil_sensing_review}
  Raphael A. Viscarra Rossel and Johan Bouma, \emph{Soil sensing: A new paradigm for agriculture},
  \url{https://www.sciencedirect.com/science/article/pii/S0308521X16303110}

\bibitem{agri_robotics}
  Tom Duckett et al., \emph{Agricultural Robotics: The Future of Robotic Agriculture},
  \url{https://research.manchester.ac.uk/en/publications/agricultural-robotics-the-future-of-robotic-agriculture/}

\bibitem{ros2_nav2}
  Open Robotics, \emph{Navigation 2 — ROS 2 Navigation Framework},
  \url{https://navigation.ros.org/}

\bibitem{rtk_gps}
  SparkFun Electronics, \emph{ZED-F9P GPS-RTK2 Board Hookup Guide},
  \url{https://learn.sparkfun.com/tutorials/gps-rtk2-hookup-guide}

% \bibitem{tinyml}
%   Pete Warden \& Daniel Situnayake, \emph{TinyML: Machine Learning with TensorFlow Lite on Arduino and Ultra-Low-Power Microcontrollers}, O'Reilly Media, 2019.

\end{thebibliography}

\end{document}

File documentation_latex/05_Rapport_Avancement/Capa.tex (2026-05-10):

\thispagestyle{empty}
\begin{table}[h!] 
\centering       

\makebox[\textwidth][c]{ 
\resizebox{\textwidth}{!}{
  
  \begin{tabular}{|cllcll|} 
  \hline
  \multicolumn{6}{|l|}{} \\ \hline
  \multicolumn{6}{|c|}{\begin{tabular}[c]{@{}c@{}}
  \\[1.5pt]
  {\Large\textbf{(UE 4.4 - Projet)}} \\[3pt] 
  {Agri-Scout : Robot Autonome pour l'Inspection}\\[1.5pt]{ Agricole et l'Analyse des Sols} \\[6pt]
  {\Large \textbf{Rapport d'avancement interne}} \\[1.5pt]
  \end{tabular}} \\ \hline
  \multicolumn{3}{|c|}{\multirow{5}{*}{\begin{tabular}[c]{@{}c@{}}\\[1.5pt] 
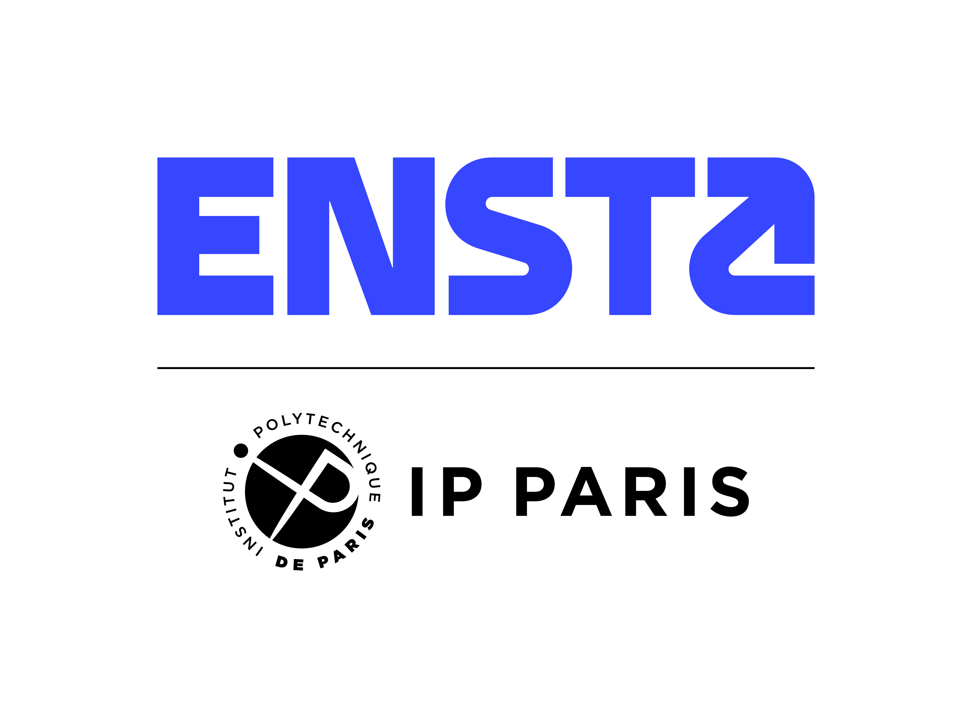
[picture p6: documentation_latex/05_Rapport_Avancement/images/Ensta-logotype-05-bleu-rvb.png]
  \small ENSTA Campus de Brest\\ \small 2 Rue François Verny\\ \small 29200 Brest Cedex 9, France\\  \end{tabular}}} & \multicolumn{3}{c|}{} \\
  \multicolumn{3}{|c|}{} & \multicolumn{3}{c|}{\multirow{8}{*}{\begin{tabular}[c]{@{}c@{}} \\ \\ \small Pedro ALVES DE ARAUJO SILVA \\ \small pedro.alves@ensta.fr\\ \small Luiz Felipe BARROS ALVES \\ \small luiz.barros@ensta.fr \\

  \end{tabular}}} \\
  \multicolumn{3}{|c|}{} & \multicolumn{3}{c|}{} \\
  \multicolumn{3}{|c|}{} & \multicolumn{3}{c|}{} \\
  \multicolumn{3}{|c|}{} & \multicolumn{3}{c|}{} \\
  \multicolumn{3}{|c|}{} & \multicolumn{3}{c|}{} \\
  \multicolumn{3}{|c|}{} & \multicolumn{3}{c|}{} \\
  \multicolumn{3}{|c|}{} & \multicolumn{3}{c|}{} \\
  \multicolumn{3}{|c|}{} & \multicolumn{3}{c|}{} \\
  \multicolumn{3}{|c|}{} & \multicolumn{3}{c|}{} \\ \hline
  \end{tabular}

}}

\end{table}

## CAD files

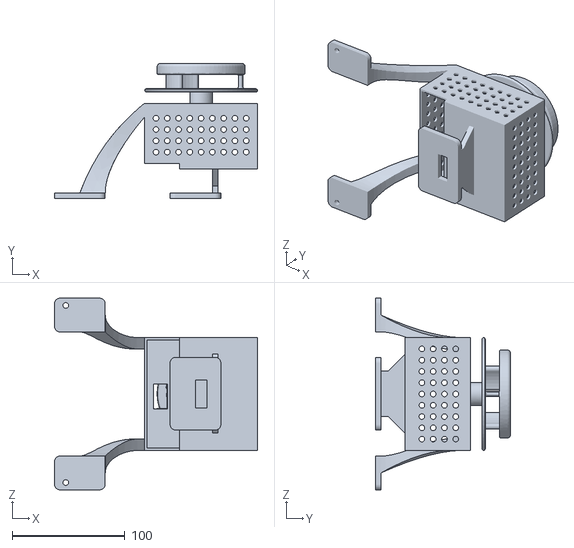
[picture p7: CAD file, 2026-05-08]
mechanical/elevation_lidar.stl
180.0 x 120.0 x 170.0

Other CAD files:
mechanical/battery2.2A_supoport.ipt
mechanical/battery5A_supoport.ipt
mechanical/bottom_support.ipt
mechanical/motor_support.ipt
mechanical/sensor_support.ipt
mechanical/support_imu_lidar.ipt
mechanical/test_sensor.ipt

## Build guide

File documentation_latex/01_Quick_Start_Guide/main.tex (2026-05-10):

\documentclass [12pt, a4paper]{article}

% Acentos e Francês
\usepackage[utf8]{inputenc}
\usepackage[french]{babel}
\usepackage{wrapfig}
\usepackage[pdftex]{color,graphicx}
\usepackage{mathrsfs}
\usepackage[labelformat = empty]{subcaption}
\usepackage[justification=centering]{caption}
\usepackage[]{multirow}
\usepackage{float}
\usepackage{tabularx}
\usepackage{booktabs}
\usepackage[usenames,dvipsnames,svgnames,table]{xcolor}
\usepackage{siunitx}
\usepackage{upquote}
\usepackage{amsmath}
\usepackage{hyperref}

% Margens
\usepackage[top=3cm, bottom=3cm, left=3cm, right=3cm]{geometry}
% Fonte
\usepackage[T1]{fontenc}
\usepackage{fancyhdr} 
\pagestyle{fancy}     

\fancyhf{}             
\lhead{UE 4.4 - Projet \hfill \thepage}

\begin{document}

% Capa de apresentação
\input{Capa}

% Sumário
\renewcommand{\contentsname}{\centering Sommaire}
\tableofcontents
\thispagestyle{empty} 
\setcounter{page}{0} 

\newpage
\section{Introduction}
Ce document est le Quick Start Guide. Il contient les étapes essentielles pour assembler, mettre sous tension et démarrer une mission d'inspection autonome avec l'Agri-Scout.

\section{Identification des Composants}
Avant de commencer, familiarisez-vous avec les éléments clés du robot (voir figure \ref{fig:robot_vue}) :
\begin{itemize}
    \item Châssis principal : supporte les 4 roues motrices.
    \item Interrupteur de puissance : situé à l'arrière, il alimente les moteurs.
    \item Câbles d'alimentation : connecteurs XT60 pour les batteries LiPo.
    \item Capteurs : RPLiDAR A1 (au sommet), Webcam USB (à l'avant).
    \item Sonde d'inspection : mécanisme à vis situé à l'avant pour l'échantillonnage du sol.
    \item Électronique embarquée : Raspberry Pi 4 et Arduino Uno (sous la plaque supérieure).
\end{itemize}

\begin{figure}[H]
    \centering
    
    \caption{Aperçu général du robot Agri-Scout.}
    \label{fig:robot_vue}
\end{figure}

\section{Prérequis Matériels}
Pour démarrer le robot, il faut s'assurer d'avoir les éléments suivants :
\begin{itemize}
    \item 2 Batteries LiPo (pour les moteurs et ponts en H L298N).
    \item Powerbank USB-C (pour alimenter le Raspberry Pi de manière isolée afin d'éviter les chutes de tension "brown-outs").
    % \item Câble USB de données entre le Raspberry Pi et l'Arduino (le fil rouge 5V a été coupé pour isoler les alimentations, mais le GND commun est impératif).
\end{itemize}

\section{Procédure de Démarrage}
\subsection{Mise sous tension}
\begin{enumerate}
    \item Connectez la Powerbank au Raspberry Pi. 
    Attendez que le système d'exploitation démarre. La Raspberry a été fixée en dessous du châssis supérieur pour bien diviser tous les composants atachés au robot. 
    L'image \ref{fig:pi} montre la position du Raspberry Pi.

\begin{figure}[H]
    \centering
    \begin{minipage}{0.48\textwidth}
        \centering
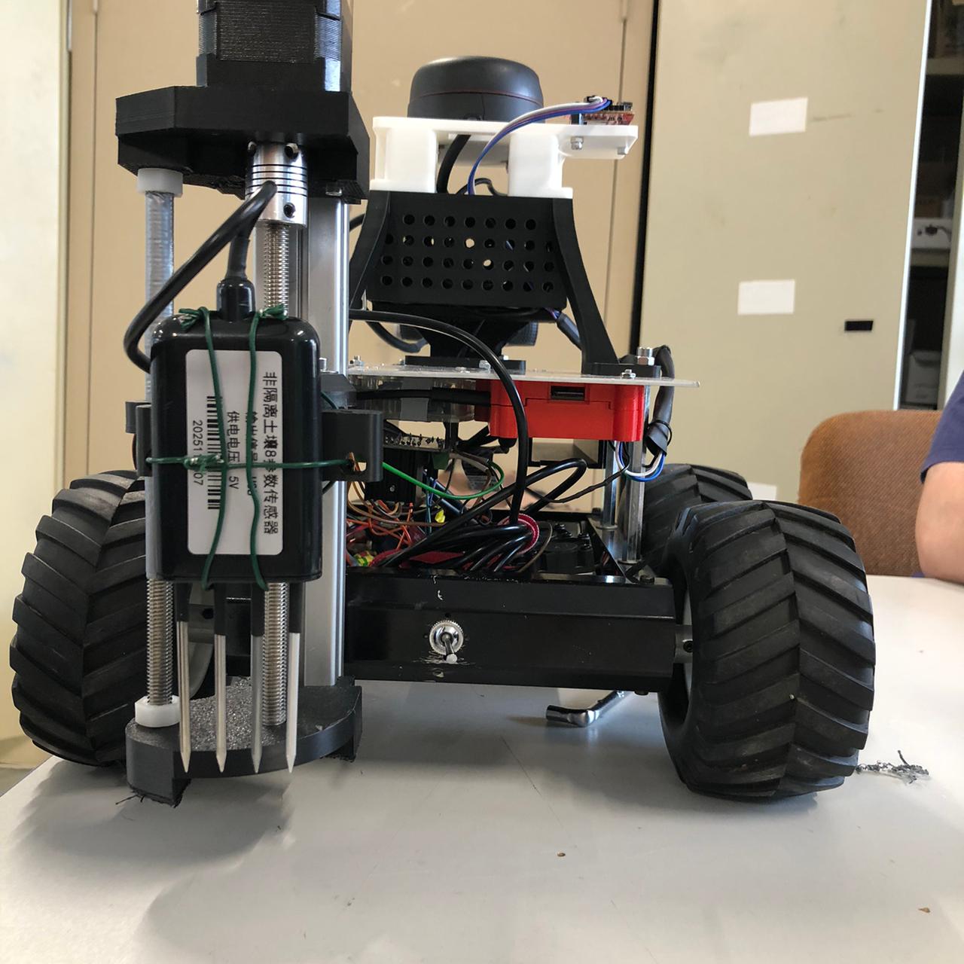
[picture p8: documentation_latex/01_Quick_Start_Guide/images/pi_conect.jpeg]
        
    \end{minipage}
    \hfill
    \begin{minipage}{0.48\textwidth}
        \centering
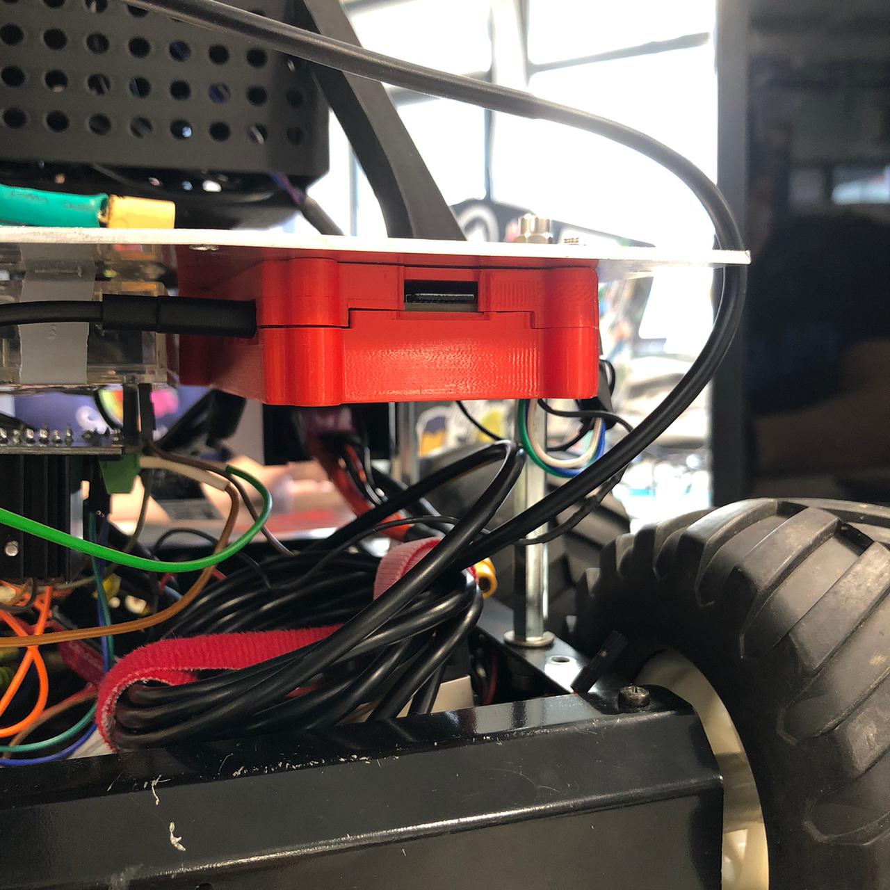
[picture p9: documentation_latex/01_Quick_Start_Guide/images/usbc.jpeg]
         
    \end{minipage}
    \caption{Raspberry Pi fixé sous le châssis supérieur et cable USB-C.}
    \label{fig:pi}
\end{figure}

    \item Insérez la batterie LiPo 5000mAh dans votre support et branchez-la au circuit de puissance des moteurs, ensuite activez l'interrupteur,
     comme le montrent les images ci-dessous.

    \begin{figure}[H]
    \centering
    \begin{minipage}{0.48\textwidth}
        \centering
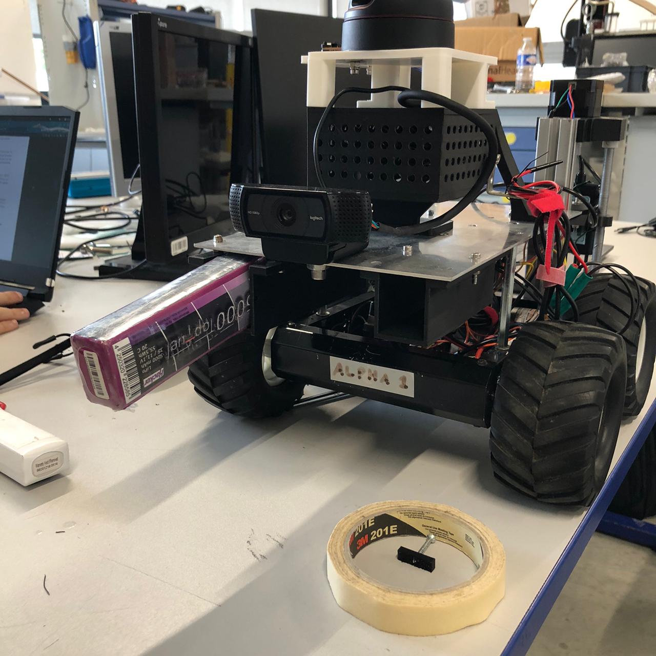
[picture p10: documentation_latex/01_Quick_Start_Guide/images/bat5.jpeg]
        
    \end{minipage}
    \hfill
    \begin{minipage}{0.48\textwidth}
        \centering
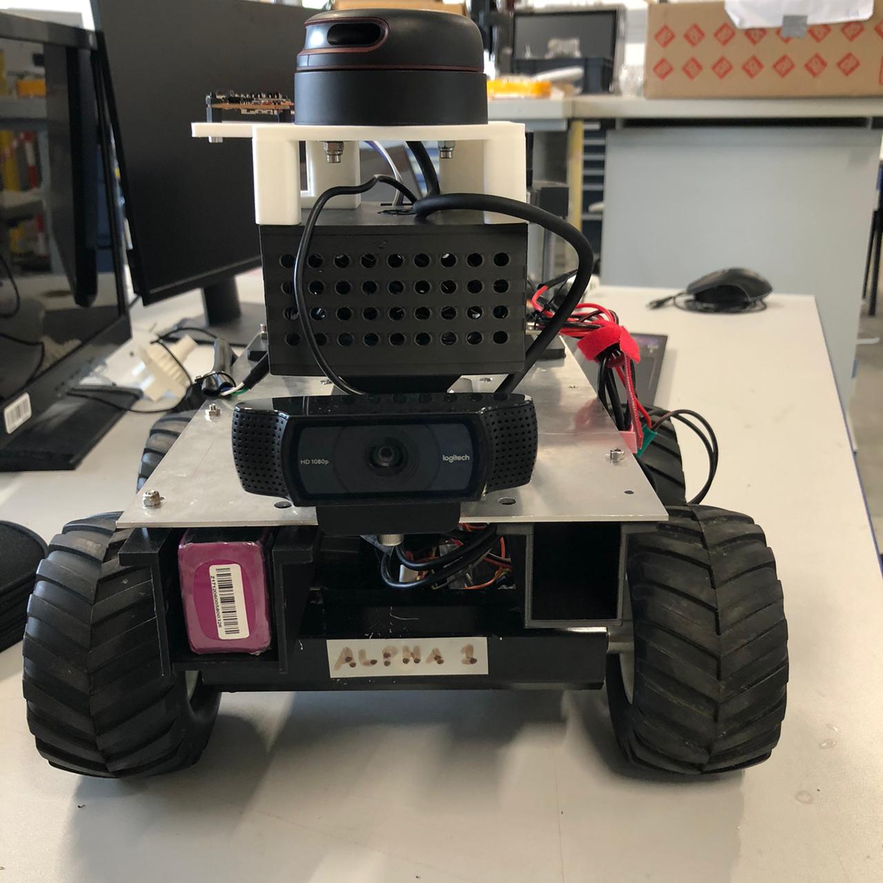
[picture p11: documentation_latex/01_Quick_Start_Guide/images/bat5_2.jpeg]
         
    \end{minipage}
    \hfill
    \begin{minipage}{0.48\textwidth}
        \centering
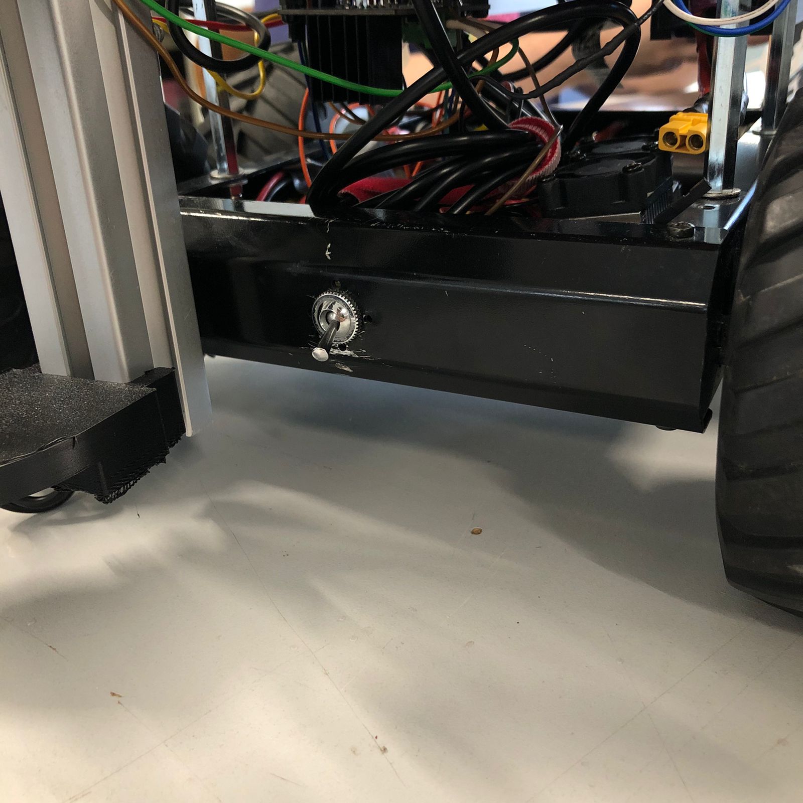
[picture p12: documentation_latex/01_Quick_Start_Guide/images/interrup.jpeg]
         
    \end{minipage}
    \caption{Batterie LiPo 5000mAh et interrupteur d'activation.}
    \label{fig:bat_5A}
\end{figure}
        Assurez-vous que les moteurs réagissent à l'activation de l'alimentation (le bruit des ESC des moteurs est un bon signe).

    \item Branchez la batterie LiPo 2200mAh au deuxième câble d'alimentation pour bien activer le moteur pas-à-pas qui est 
    responsable de monter et descendre la sonde à vis. 
    \begin{figure}[H]
    \centering
    \begin{minipage}{0.48\textwidth}
        \centering
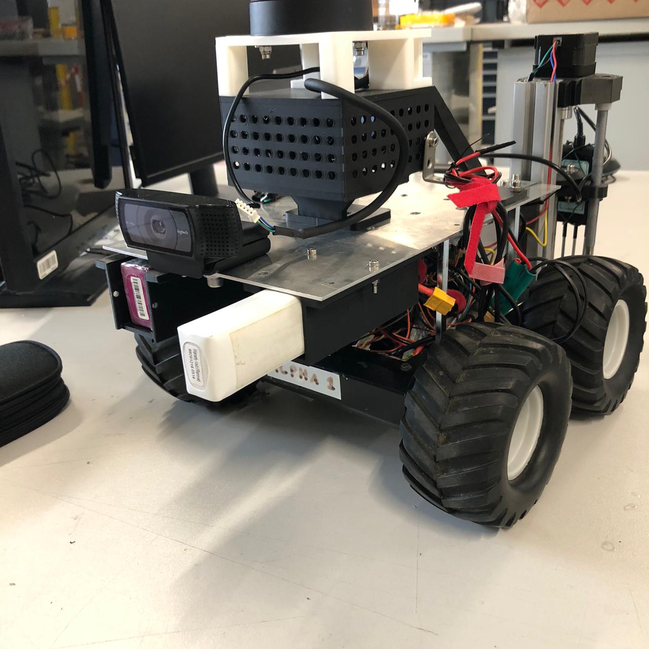
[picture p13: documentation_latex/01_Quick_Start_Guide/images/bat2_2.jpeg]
        
    \end{minipage}
    \hfill
    \begin{minipage}{0.48\textwidth}
        \centering
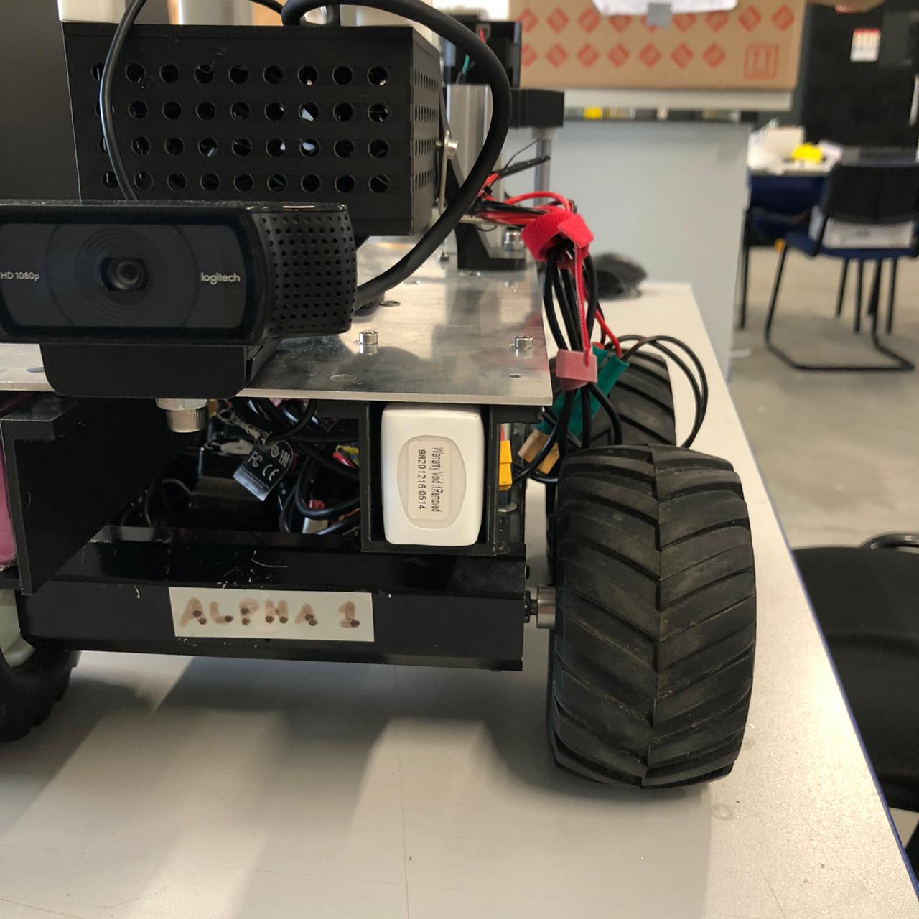
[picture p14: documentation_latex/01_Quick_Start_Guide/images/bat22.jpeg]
        
    \end{minipage}
    \caption{Batterie LiPo 2200mAh.}
    \label{fig:bat_2200mAh}
\end{figure}
\end{enumerate}

\subsection{Démarrage Logiciel}

Pour se connecter au Raspberry Pi pour la première fois, vous devez utiliser un cable Ethernet pour connecter le Raspberry Pi à votre ordinateur.
D'abord, il faut metre en place des configurations sur votre ordinateur. Les instructions suivantes sont pour les systèmes Linux. Comme en general,
la langua de configuration est en anglais, les instructions sont écrites en anglais pour éviter les confusions.
\begin{enumerate}
    \item Open Settings $\rightarrow$ Network;
    \item Locate the Wired connection;
    \item Open the IPv4 tab;
    \item Change Method from Automatic (DHCP) to Shared to other computers;
    \item Click Apply;
    \item Disable and re-enable the wired connection to restart the interface.
\end{enumerate}
Avec cette configuration, votre ordinateur agira comme un serveur DHCP pour le Raspberry Pi, lui attribuant une adresse IP automatiquement.

La deuxième étape est de se connecter au Raspberry Pi en utilisant SSH. Ouvrez un terminal et tapez la commande suivante :
\begin{verbatim}
arp -a
\end{verbatim}
Cette commande affichera une liste des appareils connectés à votre réseau local. 
Trouvez l'adresse IP associée au Raspberry Pi, généralement 10.42.0.x, et connectez-vous en utilisant la commande SSH suivante :
\begin{verbatim}
ssh ubuntu@10.42.0.x
\end{verbatim}
Le mot de passe est : \texttt{agribot}.

Une connexion sans fil est également possible si le Raspberry Pi est configuré au préalable pour rejoindre un réseau Wi-Fi local.

Une fois connecté en SSH au Raspberry Pi, exécutez le script d'initialisation principal :
\begin{verbatim}
source /opt/ros/jazzy/setup.bash

cd ~/AGRI-Scout_Modif

source install/setup.bash

ros2 launch ~/AGRI-Scout_Modif/demo.launch.py
\end{verbatim}

Ce fichier se charge de lancer :
\begin{itemize}
    \item Le nœud de la caméra (V4L2).
    \item Le nœud du RPLiDAR.
    \item Le contrôleur de vision et de mouvement Python (\texttt{agri\_line\_follower.py}).
\end{itemize}

\end{document}

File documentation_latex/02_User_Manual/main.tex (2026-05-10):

\documentclass [12pt, a4paper]{article}

% Acentos e Français
\usepackage[utf8]{inputenc}
\usepackage[french]{babel}
\usepackage{wrapfig}
\usepackage[pdftex]{color,graphicx}
\usepackage{mathrsfs}
\usepackage[labelformat = empty]{subcaption}
\usepackage[justification=centering]{caption}
\usepackage[]{multirow}
\usepackage{float}
\usepackage{tabularx}
\usepackage{booktabs}
\usepackage[usenames,dvipsnames,svgnames,table]{xcolor}
\usepackage{siunitx}
\usepackage{upquote}
\usepackage{amsmath}
\usepackage{hyperref}
\usepackage{enumitem}

% Margens
\usepackage[top=3cm, bottom=3cm, left=3cm, right=3cm]{geometry}
% Fonte
\usepackage[T1]{fontenc}
\usepackage{fancyhdr} 
\pagestyle{fancy}     

\fancyhf{}             
\lhead{UE 4.4 - Projet \hfill \thepage}

\begin{document}

% Capa de apresentação
\input{Capa}

% Sumário
\renewcommand{\contentsname}{\centering Sommaire}
\tableofcontents
\thispagestyle{empty} 
\setcounter{page}{0} 

\newpage
\section{Introduction}
Ce User Manual décrit en détail toutes les utilisations supportées par l'Agri-Scout dans des conditions nominales de fonctionnement. Il s'adresse à l'opérateur final souhaitant comprendre et exploiter l'ensemble des fonctionnalités du robot : mission autonome, téléopération manuelle, acquisition de données pédologiques et surveillance à distance.

L'Agri-Scout est un robot agricole différentiel à quatre roues, équipé d'une caméra USB, d'un LIDAR RPLiDAR A1 et d'une sonde à vis motorisée pour l'analyse du sol. Il est piloté par un Raspberry Pi 4 sous ROS 2 Jazzy, communicant avec un Arduino UNO pour le contrôle des actionneurs.

Avant toute utilisation, l'opérateur doit s'assurer que le robot a été correctement mis sous tension en suivant le Quick Start Guide.

% ============================================================
\section{Modes d'Utilisation}

L'Agri-Scout supporte trois modes d'utilisation principaux, sélectionnables selon le scénario opérationnel :

\begin{table}[H]
\centering
\begin{tabularx}{\textwidth}{lX}
\toprule
\textbf{Mode} & \textbf{Description} \\
\midrule
Mission Autonome & Suivi de ligne + récolte automatique. Mode de travail principal. \\
Téléopération & Contrôle manuel du robot depuis un terminal distant via SSH. \\
Démonstration (Hunter) & Le robot localise et s'approche d'un objet coloré (drapeau/token). \\
\bottomrule
\end{tabularx}
\caption{Modes d'utilisation de l'Agri-Scout.}
\end{table}

% ============================================================
\section{Mode 1 : Mission Autonome}

\subsection{Description générale}
Dans ce mode, le robot navigue de façon entièrement autonome le long d'une piste balisée par une ligne blanche tracée au sol. À intervalles réguliers (toutes les 30 secondes), ou lorsqu'il détecte un marqueur de récolte rouge, il s'arrête, déploie sa sonde dans le sol pour collecter des données pédologiques, puis reprend sa trajectoire.

\subsection{Lancement de la mission}
Après connexion SSH au Raspberry Pi (voir Quick Start Guide), exécutez la séquence suivante :
\begin{verbatim}
source /opt/ros/jazzy/setup.bash
cd ~/AGRI-Scout_Modif
source install/setup.bash
ros2 launch ~/AGRI-Scout_Modif/demo.launch.py
\end{verbatim}

Ce fichier de lancement démarre simultanément :
\begin{itemize}
    \item Le nœud de la caméra (\texttt{v4l2\_camera\_node}) sur le topic \texttt{/image\_raw}.
    \item Le nœud du LIDAR RPLiDAR (\texttt{rplidar\_composition}) sur le topic \texttt{/scan}.
    \item Le nœud de contrôle principal (\texttt{agri\_line\_follower.py}).
\end{itemize}

\subsection{Suivi de ligne}
Le robot identifie la piste blanche à l'aide de sa caméra pointée vers le sol. Un algorithme de segmentation HSV isole les pixels blancs dans une zone d'intérêt (50\% inférieur de l'image). Un correcteur PD calcule l'erreur de position latérale du centroïde de la ligne par rapport au centre de l'image et ajuste la différence de vitesse entre les roues gauche et droite pour corriger la trajectoire.

Les seuils HSV par défaut pour la ligne blanche sont :
\begin{table}[H]
\centering
\begin{tabular}{lcc}
\toprule
\textbf{Canal} & \textbf{Min} & \textbf{Max} \\
\midrule
H (Teinte) & 0 & 255 \\
S (Saturation) & 0 & 60 \\
V (Valeur) & 160 & 255 \\
\bottomrule
\end{tabular}
\caption{Seuils HSV de détection de la ligne blanche.}
\end{table}

\subsection{Détection d'obstacles (LIDAR)}
En permanence, le nœud surveille les mesures du LIDAR dans un secteur de $\pm30°$ centré sur l'avant du robot. Si un obstacle est détecté à moins de 20 cm, le robot s'arrête automatiquement et attend que la voie soit dégagée avant de reprendre.

\subsection{Déclenchement de la récolte}

La séquence de récolte peut être déclenchée de deux façons :

\begin{enumerate}
    \item Par minuterie automatique : toutes les 30 secondes d'opération en mode FOLLOWING, le robot lance automatiquement une récolte, quelle que soit sa position.
    \item Par marqueur visuel : lorsque la caméra détecte une zone rouge (seuil HSV H: 0--10, S: 120--255, V: 70--255) dont l'aire dépasse le seuil configuré (500 pixels par défaut), le robot lance la séquence de récolte.
\end{enumerate}

\subsection{Séquence de récolte}
\begin{enumerate}
    \item Arrêt complet des moteurs de traction (\texttt{CMD X}).
    \item Descente de la sonde : le moteur pas à pas tourne pendant 15,5 secondes pour enfoncer la sonde dans le sol (\texttt{CMD D}).
    \item Collecte de données : le robot reste immobile pendant 10 secondes. Durant cette phase, le capteur NPK (si connecté) peut enregistrer les paramètres du sol.
    \item Remontée de la sonde : le moteur pas à pas remonte la sonde pendant 15,5 secondes (\texttt{CMD U}).
    \item Avance de dégagement : le robot avance à vitesse réduite pendant 4 secondes pour quitter la zone de récolte et retrouver la ligne (\texttt{CMD F 20}).
    \item Retour au mode FOLLOWING.
\end{enumerate}

La durée totale d'une séquence de récolte est d'environ 45 secondes.

\subsection{Arrêt de la mission}
Pour arrêter proprement la mission, appuyez sur \texttt{Ctrl+C} dans le terminal SSH. Le nœud envoie automatiquement une commande d'arrêt (\texttt{CMD X}) à l'Arduino avant de se terminer. L'Arduino dispose également d'un watchdog interne : si aucune commande n'est reçue pendant plus d'une seconde, les moteurs sont coupés automatiquement.

% ============================================================
\section{Mode 2 : Téléopération Manuelle}

\subsection{Description}
Ce mode permet à l'opérateur de contrôler le robot directement depuis un terminal, sans logique autonome. Il est utile pour les déplacements de positionnement, les tests de mobilité ou la calibration mécanique.

\subsection{Lancement}
Dans un terminal SSH, exécutez :
\begin{verbatim}
source /opt/ros/jazzy/setup.bash
cd ~/AGRI-Scout_Modif
source install/setup.bash
python3 python_control/ros2_teleop.py
\end{verbatim}

\subsection{Commandes clavier}
\begin{table}[H]
\centering
\begin{tabular}{cl}
\toprule
\textbf{Touche} & \textbf{Action} \\
\midrule
\texttt{W} & Avancer \\
\texttt{S} & Reculer \\
\texttt{A} & Tourner à gauche \\
\texttt{D} & Tourner à droite \\
\texttt{ESPACE} & Arrêt complet \\
\texttt{I} & Descendre la sonde (continu) \\
\texttt{K} & Monter la sonde (continu) \\
\texttt{Q} & Quitter et arrêter le robot \\
\bottomrule
\end{tabular}
\caption{Mappage clavier de la téléopération.}
\end{table}

Note : Les commandes sont publiées sur le topic ROS 2 \texttt{agri\_commands}. Le nœud \texttt{ros2\_serial\_bridge.py} doit être actif pour relayer ces commandes vers l'Arduino. En pratique, il est conseillé d'utiliser la téléopération conjointement avec le LIDAR actif pour bénéficier de la protection anti-collision.

% ============================================================
\section{Mode 3 : Démonstration (Hunter)}

\subsection{Description}
Le mode Démonstration remplace l'algorithme de suivi de ligne par un algorithme de recherche et d'approche d'un objet coloré (drapeau, cône ou token placé sur le terrain). C'est le mode recommandé pour les présentations où un parcours de ligne n'est pas disponible.

\subsection{Lancement}
Arrêtez tout nœud actif (\texttt{Ctrl+C}), puis lancez uniquement la caméra, le LIDAR et le nœud hunter :
\begin{verbatim}
source /opt/ros/jazzy/setup.bash
cd ~/AGRI-Scout_Modif
source install/setup.bash
python3 python_control/agri_demo_hunter.py
\end{verbatim}

Note : Le nœud de la caméra et le nœud du LIDAR doivent être lancés séparément ou via un fichier de lancement adapté.

\subsection{Comportement}
\begin{enumerate}
    \item SEARCHING : le robot tourne lentement sur lui-même à la recherche d'un objet rouge/orange dans son champ de vision.
    \item TRACKING : dès que l'objet est détecté, le robot s'aligne et avance vers lui. Un contrôleur proportionnel corrige la trajectoire latéralement.
    \item HARVESTING : lorsque l'objet occupe une surface suffisante dans l'image (seuil : 15 000 pixels à résolution 320×240), le robot s'arrête et lance la séquence de récolte.
\end{enumerate}

La couleur cible par défaut (rouge/orange) peut être ajustée dans le fichier \texttt{agri\_demo\_hunter.py} en modifiant les variables \texttt{lower\_color} et \texttt{upper\_color} (format HSV NumPy).

% ============================================================
\section{Acquisition de Données Pédologiques}

\subsection{Description}
Le capteur de sol NPK (connecté sur \texttt{/dev/ttyUSB1}) mesure 8 paramètres en continu via le protocole Modbus RTU. Ce script s'exécute indépendamment de ROS 2 et peut être lancé en parallèle d'une mission autonome ou manuellement lors d'une inspection statique.

\subsection{Lancement}
\begin{verbatim}
python3 python_control/read_sensor.py
\end{verbatim}

\subsection{Paramètres mesurés}
\begin{table}[H]
\centering
\begin{tabular}{ll}
\toprule
\textbf{Paramètre} & \textbf{Unité} \\
\midrule
Température du sol & °C \\
Humidité du sol & \% \\
Conductivité électrique & µS/cm \\
Salinité & mg/L \\
Azote (N) & mg/kg \\
Phosphore (P) & mg/kg \\
Potassium (K) & mg/kg \\
pH & --- \\
\bottomrule
\end{tabular}
\caption{Paramètres pédologiques mesurés par le capteur NPK.}
\end{table}

Les données sont affichées en temps réel dans le terminal. À l'arrêt (\texttt{Ctrl+C}), elles sont automatiquement sauvegardées dans un fichier \texttt{sensor\_data\_log\_corrigido.csv} dans le répertoire courant.

% ============================================================
\section{Surveillance à Distance (RQT Image View)}

\subsection{Description}
L'opérateur peut visualiser le flux vidéo traité par l'algorithme OpenCV depuis un PC connecté au même réseau que le Raspberry Pi. Ce flux indique en temps réel les contours détectés, le centroïde de la ligne et l'état du robot.

\subsection{Configuration réseau}
Assurez-vous que les deux machines partagent le même \texttt{ROS\_DOMAIN\_ID} :
\begin{verbatim}
export ROS_DOMAIN_ID=0
export ROS_LOCALHOST_ONLY=0
\end{verbatim}

\subsection{Lancement sur le PC de l'opérateur}
\begin{verbatim}
source /opt/ros/jazzy/setup.bash
ros2 run rqt_image_view rqt_image_view
\end{verbatim}
Sélectionnez le topic \texttt{/agri\_debug} dans le menu déroulant pour visualiser l'image annotée. Le flux est émis à un rythme réduit (1 trame sur 15) pour économiser la bande passante Wi-Fi.

% ============================================================
\section{Calibration Mécanique de la Sonde}

\subsection{Description}
Avant la première utilisation, ou après démontage mécanique, il est nécessaire de calibrer la course maximale de la sonde à vis pour éviter de détériorer la mécanique.

\subsection{Procédure}
\begin{enumerate}
    \item Suspendez le robot ou placez-le sur une surface sans obstacles sous la sonde.
    \item Connectez-vous en SSH au Raspberry Pi.
    \item Lancez le script de calibration :
\begin{verbatim}
python3 python_control/calibrate_probe.py
\end{verbatim}
    \item Entrez un nombre de pas positif (ex. \texttt{50}) pour descendre la sonde, ou négatif (ex. \texttt{-50}) pour la remonter.
    \item Notez la valeur affichée comme « distance relative comptée » lorsque la sonde atteint sa butée inférieure. Cette valeur correspond au nombre de pas total du course mécanique.
    \item Appuyez sur \texttt{Ctrl+C} ou entrez \texttt{0} pour quitter.
\end{enumerate}

Utilisez de petites valeurs (10 à 20 pas) lorsque vous approchez de la butée mécanique pour éviter de forcer le moteur.

% ============================================================
\section{Consignes de Sécurité}

\begin{itemize}
    \item Ne jamais lancer le robot en espace confiné sans vérifier que le LIDAR est actif et fonctionnel.
    \item Toujours couper l'alimentation des batteries LiPo après utilisation pour éviter la décharge profonde.
    \item Ne pas approcher les mains du mécanisme de la sonde lorsqu'une séquence de récolte est en cours.
    \item En cas de comportement anormal, couper l'interrupteur de la batterie moteur immédiatement. Le Watchdog Arduino arrêtera les moteurs dans la seconde.
    \item Ne pas exposer les batteries LiPo à une chaleur excessive ou à des chocs mécaniques.
\end{itemize}

% ============================================================
\section{Résolution de Problèmes Courants}

\begin{table}[H]
\centering
\begin{tabularx}{\textwidth}{lX}
\toprule
\textbf{Symptôme} & \textbf{Solution} \\
\midrule
Le robot ne démarre pas sa mission & Vérifiez que l'Arduino est connecté via USB et que le port \texttt{/dev/ttyACM0} est accessible. Consultez les logs du nœud. \\
\addlinespace
Le robot ne suit pas la ligne & Vérifiez l'éclairage ambiant. Ajustez les seuils HSV (\texttt{line\_v\_lo}) dans le lancement ROS 2. \\
\addlinespace
Arrêt intempestif à chaque démarrage & Le LIDAR détecte un obstacle. Vérifiez que la zone frontale est dégagée sur au moins 20 cm. \\
\addlinespace
La sonde ne descend pas & Vérifiez que la batterie LiPo 2200mAh est branchée et que le pont en H L298N est actif (LED allumée). \\
\addlinespace
Pas d'image sur \texttt{/agri\_debug} & Vérifiez que le \texttt{ROS\_DOMAIN\_ID} est identique sur le Pi et sur le PC. \\
\addlinespace
Erreur \texttt{Serial: No device} & L'Arduino n'est pas détecté. Reconnectez le câble USB. Vérifiez avec \texttt{ls /dev/ttyACM*}. \\
\bottomrule
\end{tabularx}
\caption{Problèmes courants et solutions.}
\end{table}

\end{document}

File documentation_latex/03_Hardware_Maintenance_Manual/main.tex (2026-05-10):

\documentclass [12pt, a4paper]{article}

% Acentos e Français
\usepackage[utf8]{inputenc}
\usepackage[french]{babel}
\usepackage{wrapfig}
\usepackage[pdftex]{color,graphicx}
\usepackage{mathrsfs}
\usepackage[labelformat = empty]{subcaption}
\usepackage[justification=centering]{caption}
\usepackage[]{multirow}
\usepackage{float}
\usepackage{tabularx}
\usepackage{booktabs}
\usepackage[usenames,dvipsnames,svgnames,table]{xcolor}
\usepackage{siunitx}
\usepackage{upquote}
\usepackage{amsmath}
\usepackage{hyperref}
\usepackage{enumitem}

% Margens
\usepackage[top=3cm, bottom=3cm, left=3cm, right=3cm]{geometry}
% Fonte
\usepackage[T1]{fontenc}
\usepackage{fancyhdr}
\pagestyle{fancy}

\fancyhf{}
\lhead{UE 4.4 - Projet \hfill \thepage}

\begin{document}

% Capa de apresentação
\input{Capa}

% Sumário
\renewcommand{\contentsname}{\centering Sommaire}
\tableofcontents
\thispagestyle{empty}
\setcounter{page}{0}

\newpage
\section{Introduction}
Ce Hardware Maintenance Manual est le document de référence technique pour la maintenance, le démontage, le remplacement de pièces et le débogage matériel du robot Agri-Scout. Il s'adresse à un technicien souhaitant intervenir sur la mécanique ou l'électronique du robot après une panne ou une usure normale.

La majeure partie de la structure mécanique a été conçue et fabriquée par l'équipe : les pièces en plastique sont imprimées en 3D (FDM, PLA) à partir de fichiers CAO Autodesk Inventor, et les supports métalliques sont découpés et percés en laboratoire.

Avant toute intervention : coupez l'interrupteur des batteries LiPo et débranchez la Powerbank du Raspberry Pi.

% ============================================================
\section{Vue d'Ensemble du Robot}

La figure \ref{fig:robot_vue} présente le robot Agri-Scout assemblé, prêt pour une mission.

\begin{figure}[H]
    \centering
    
    \caption{Robot Agri-Scout assemblé.}
    \label{fig:robot_vue}
\end{figure}

Le châssis est organisé en deux niveaux :
\begin{itemize}
    \item Niveau inférieur (châssis d'origine) : moteurs de traction, ESC, câblage de puissance.
    \item Niveau supérieur (plaque aluminium) : Raspberry Pi, Arduino, pont en H, batteries, capteurs.
\end{itemize}

\begin{figure}[H]
    \centering
    \begin{minipage}{0.48\textwidth}
        \centering
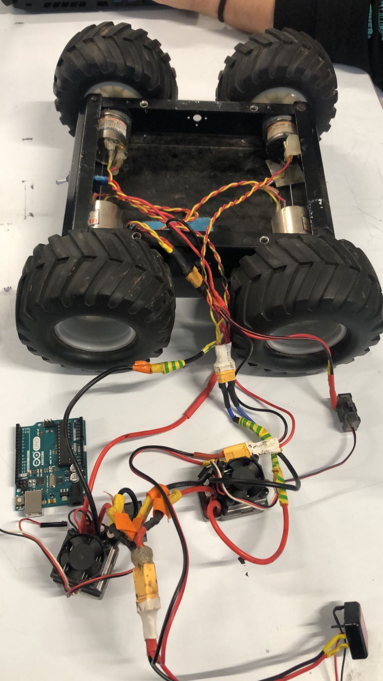
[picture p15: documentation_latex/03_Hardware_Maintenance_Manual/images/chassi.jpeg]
        
    \end{minipage}
    \hfill
    \begin{minipage}{0.48\textwidth}
        \centering
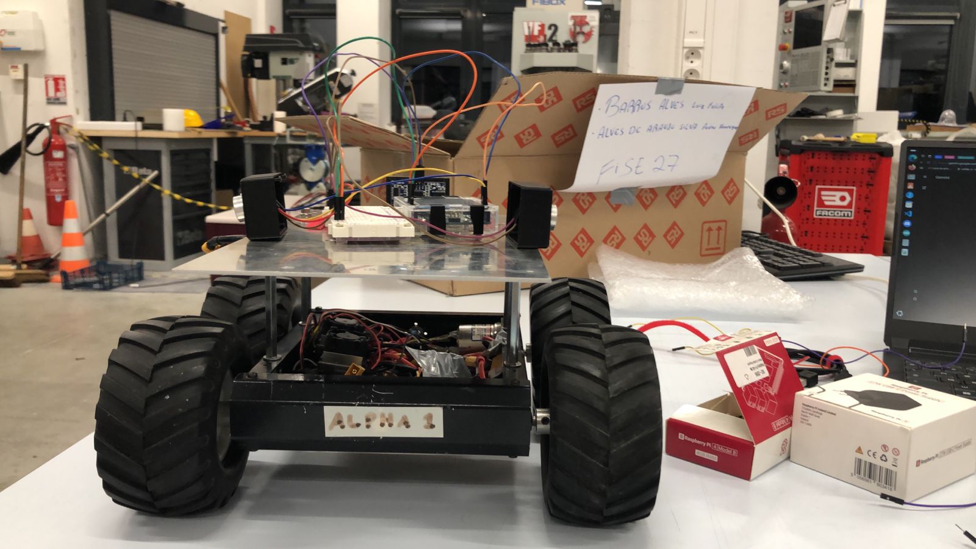
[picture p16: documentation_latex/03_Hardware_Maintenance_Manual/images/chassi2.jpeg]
        
    \end{minipage}
    \caption{Châssis de base (gauche) et châssis avec second étage aluminium (droite).}
    \label{fig:chassis}
\end{figure}

% ============================================================
\section{Référence des Composants}

\begin{table}[H]
\centering
\begin{tabularx}{\textwidth}{llX}
\toprule
\textbf{Composant} & \textbf{Référence / Modèle} & \textbf{Remarques} \\
\midrule
Microcontrôleur principal & Raspberry Pi 4 Model B (4 Go) & Système Ubuntu 22.04, ROS 2 Jazzy \\
Microcontrôleur secondaire & Arduino UNO R3 & Firmware \texttt{main\_firmware.ino} \\
Moteurs de traction & Moteurs DC brushed (4×) & Contrôlés par 2 ESC RC \\
ESC des roues & ESC RC standard (2×) & Pins 9 et 10 de l'Arduino \\
Moteur sonde & NEMA 17 (moteur pas à pas) & 200 pas/tour, contrôlé via L298N \\
Pont en H (sonde) & L298N & Pins 4, 5, 6, 7 de l'Arduino \\
LIDAR & Slamtec RPLiDAR A1 & USB, 115200 bauds, \texttt{/dev/ttyUSB0} \\
Caméra & Webcam USB V4L2 & 320×240 MJPEG, \texttt{/dev/video0} \\
IMU & SparkFun OpenLog Artemis & Communication UART \\
Capteur sol & Capteur NPK 8 paramètres & RS485/Modbus RTU, \texttt{/dev/ttyUSB1} \\
Batterie moteurs & LiPo 5000 mAh (11.1 V, 3S) & Circuit de puissance des roues \\
Batterie sonde & LiPo 2200 mAh (11.1 V, 3S) & Alimentation pont en H L298N \\
Alimentation Raspberry Pi & Powerbank USB-C 5 V & Isolation du bruit de puissance \\
\bottomrule
\end{tabularx}
\caption{Référence des composants principaux de l'Agri-Scout.}
\label{tab:composants}
\end{table}

% ============================================================
\section{Système d'Alimentation}

\subsection{Architecture électrique}
Le robot utilise trois sources d'alimentation distinctes et indépendantes pour isoler les circuits sensibles des perturbations des moteurs :

\begin{itemize}
    \item LiPo 5000 mAh (11,1 V) : alimente les moteurs de traction via les ESC.
    \item LiPo 2200 mAh (11,1 V) : alimente le pont en H L298N qui contrôle le moteur pas à pas de la sonde.
    \item Powerbank USB-C : alimente uniquement le Raspberry Pi (5 V), évitant les chutes de tension (brown-outs) lors des pics de courant moteur.
\end{itemize}

Le câble USB entre le Raspberry Pi et l'Arduino a son fil d'alimentation rouge (+5 V) coupé. Seuls le GND et les données sont connectés. La masse commune (GND) entre tous les éléments est impérative pour le bon fonctionnement des communications.

\subsection{Démontage et remplacement des batteries}

\begin{figure}[H]
    \centering
    \begin{minipage}{0.48\textwidth}
        \centering
        
    \end{minipage}
    \hfill
    \begin{minipage}{0.48\textwidth}
        \centering
        
    \end{minipage}
    \caption{Batterie LiPo 5000 mAh et son support de fixation.}
    \label{fig:bat5}
\end{figure}

\begin{figure}[H]
    \centering
    \begin{minipage}{0.48\textwidth}
        \centering
        
    \end{minipage}
    \hfill
    \begin{minipage}{0.48\textwidth}
        \centering
        
    \end{minipage}
    \caption{Batterie LiPo 2200 mAh et son emplacement.}
    \label{fig:bat22}
\end{figure}

Pour remplacer une batterie LiPo :
\begin{enumerate}
    \item Coupez l'interrupteur correspondant.
    \item Débranchez le connecteur XT60 (tirez droit, ne tordez pas).
    \item Desserrez les deux vis du support imprimé en 3D.
    \item Glissez la batterie hors de son support.
    \item Insérez la nouvelle batterie et inversez la procédure.
\end{enumerate}

\subsection{Interrupteur de puissance}

L'interrupteur (figure \ref{fig:interrupteur}) coupe uniquement l'alimentation du circuit de puissance des moteurs (LiPo 5000 mAh). La Powerbank du Raspberry Pi est indépendante et doit être débranchée séparément.

\begin{figure}[H]
    \centering
    
    \caption{Interrupteur de puissance des moteurs de traction.}
    \label{fig:interrupteur}
\end{figure}

% ============================================================
\section{Électronique : Démontage et Remplacement}

\subsection{Raspberry Pi et Arduino}

Le Raspberry Pi est fixé sous le châssis supérieur, et l'Arduino UNO est fixé dessus. Ils sont reliés par un câble USB dont le fil +5 V a été sectionné.

\begin{figure}[H]
    \centering
    \begin{minipage}{0.48\textwidth}
        \centering
        
    \end{minipage}
    \hfill
    \begin{minipage}{0.48\textwidth}
        \centering
        
    \end{minipage}
    \caption{Raspberry Pi fixé sous le châssis supérieur et connecteur USB-C de la Powerbank.}
    \label{fig:pi_arduino}
\end{figure}

\begin{figure}[H]
    \centering
    
    \caption{Vue de la disposition du Raspberry Pi et de l'Arduino sur le châssis.}
    \label{fig:pi_ino}
\end{figure}

Pour déposer le Raspberry Pi :
\begin{enumerate}
    \item Débranchez la Powerbank USB-C.
    \item Déconnectez le câble USB vers l'Arduino.
    \item Retirez les 4 vis M3 de fixation au châssis.
\end{enumerate}

Pour déposer l'Arduino :
\begin{enumerate}
    \item Notez la connexion de chaque broche avant de déconnecter (ou photographiez).
    \item Débranchez le câble USB vers le Raspberry Pi.
    \item Retirez le câble des ESC (pins 9, 10) et du pont en H (pins 4, 5, 6, 7).
    \item Retirez les vis de fixation.
\end{enumerate}

Lors du remplacement de l'Arduino, il est impératif de re-téléverser le firmware \texttt{main\_firmware.ino} (voir Developer Manual, section Compilation et Modification).

\subsection{LIDAR RPLiDAR A1}

\begin{figure}[H]
    \centering
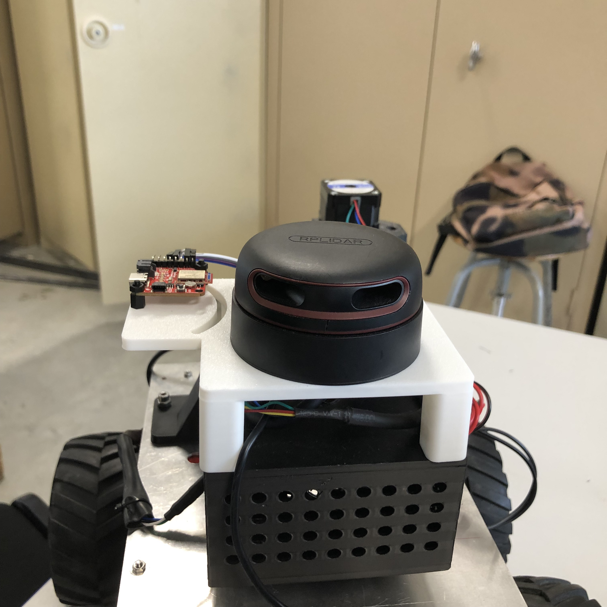
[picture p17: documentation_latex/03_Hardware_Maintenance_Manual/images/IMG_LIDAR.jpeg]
    
    \caption{RPLiDAR A1 monté sur le support d'élévation.}
    \label{fig:lidar_hw}
\end{figure}

Le LIDAR est fixé sur un support rotatif imprimé en 3D (figure \ref{fig:support_lidar}) qui permet de régler son orientation.

\begin{figure}[H]
    \centering
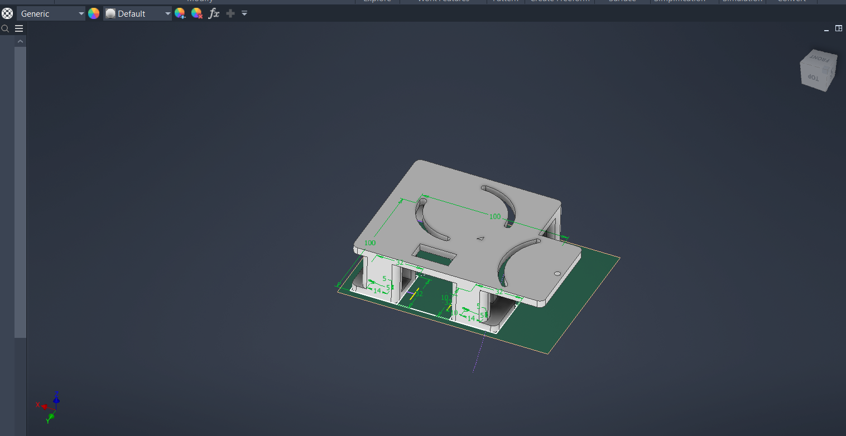
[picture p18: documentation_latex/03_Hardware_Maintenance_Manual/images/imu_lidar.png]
    
    \caption{Support de fixation rotatif pour le LIDAR et l'IMU.}
    \label{fig:support_lidar}
\end{figure}

Pour déposer le LIDAR :
\begin{enumerate}
    \item Débranchez le câble USB du Raspberry Pi.
    \item Desserrez la vis centrale du support rotatif.
    \item Soulevez le LIDAR verticalement hors de son logement.
\end{enumerate}

\subsection{IMU (SparkFun OpenLog Artemis)}

\begin{figure}[H]
    \centering
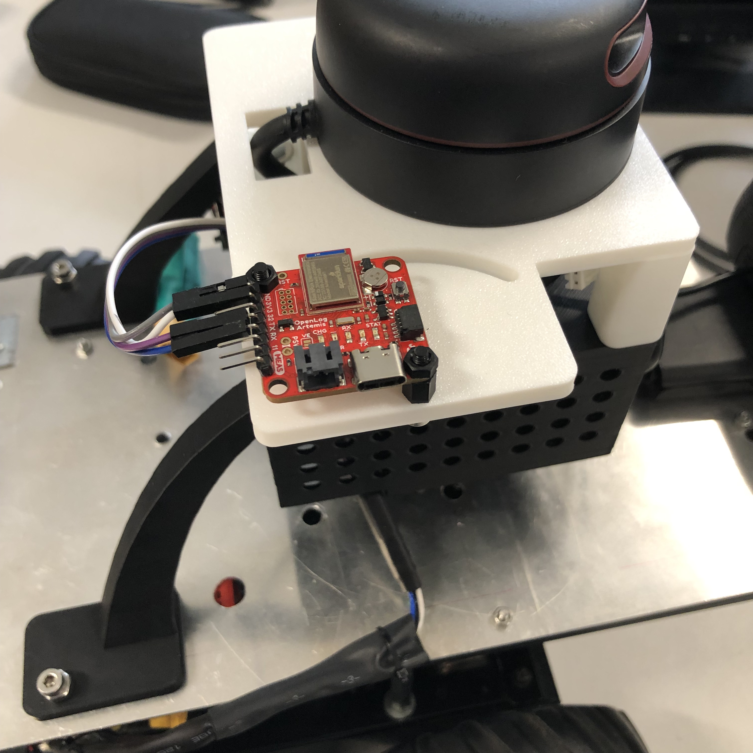
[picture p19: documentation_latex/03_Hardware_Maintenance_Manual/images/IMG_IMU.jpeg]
    
    \caption{Module SparkFun OpenLog Artemis fixé sur le support du LIDAR.}
    \label{fig:imu_hw}
\end{figure}

L'IMU est connectée au Raspberry Pi via communication UART (Serial). Pour la remplacer, débranchez les 4 fils dupont et dévissez le module de son support.

\subsection{Webcam USB}

\begin{figure}[H]
    \centering
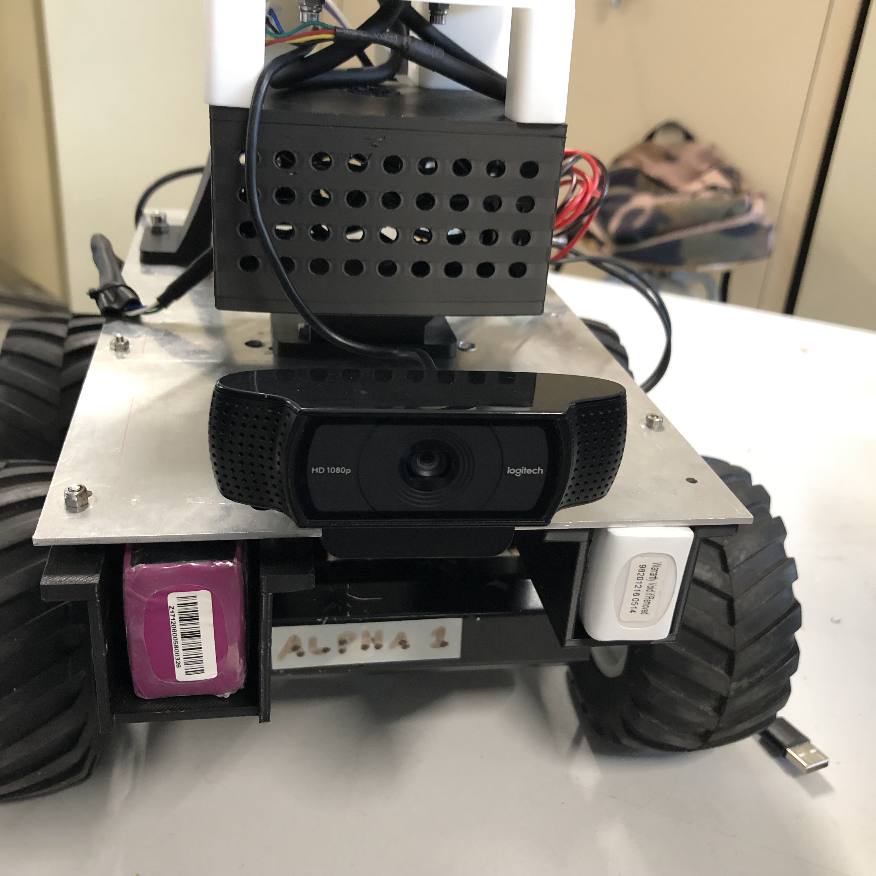
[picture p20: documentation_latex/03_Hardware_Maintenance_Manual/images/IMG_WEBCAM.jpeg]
    
    \caption{Webcam USB montée sur le châssis.}
    \label{fig:webcam_hw}
\end{figure}

La webcam est montée sur le châssis avant et reliée au Raspberry Pi par USB. Elle est fixée par une vis M3. En cas de remplacement, assurez-vous que le nouveau modèle est compatible V4L2 (\texttt{v4l2-ctl --list-devices} pour vérifier).

% ============================================================
\section{Mécanique : Pièces Imprimées en 3D}

Toutes les pièces mécaniques ont été conçues avec Autodesk Inventor. Les fichiers source sont disponibles dans le dépôt du projet. En cas de rupture, les pièces peuvent être réimprimées directement (matériau recommandé : PLA, remplissage $\geq$ 40\%).

\subsection{Support d'élévation pour LIDAR et IMU}

\begin{figure}[H]
    \centering
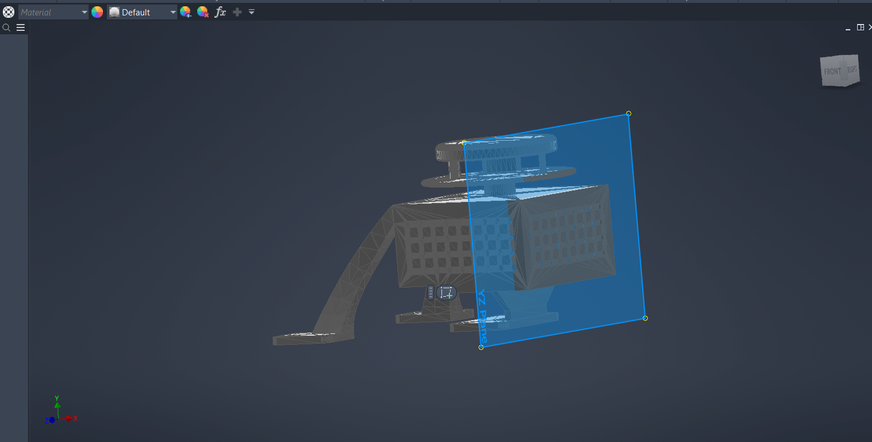
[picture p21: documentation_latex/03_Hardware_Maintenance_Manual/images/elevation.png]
    
    \caption{Conception CAO du support d'élévation (LIDAR et IMU).}
    \label{fig:elevation}
\end{figure}

Ce support surélevé permet au LIDAR de scanner à 360° sans que les câbles ou le châssis ne bloquent le faisceau. Il se visse directement sur la plaque aluminium du second étage.

\subsection{Support du moteur pas à pas (sonde)}

\begin{figure}[H]
    \centering
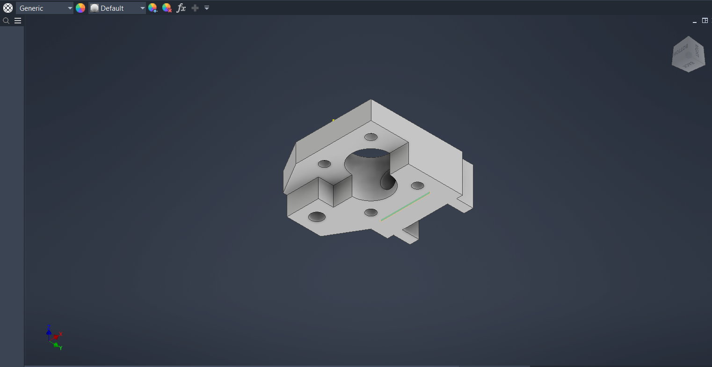
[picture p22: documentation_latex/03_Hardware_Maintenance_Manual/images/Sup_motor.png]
    
    \caption{Conception CAO du support du moteur NEMA 17.}
    \label{fig:sup_motor}
\end{figure}

Ce support encaisse les forces de torsion lors de la pénétration de la sonde dans le sol. En cas de rupture (point de fragilité : l'axe de fixation du moteur), réimprimer avec un remplissage de 60\% minimum.

Pour le remplacement du moteur NEMA 17 :
\begin{enumerate}
    \item Coupez l'alimentation de la batterie LiPo 2200 mAh.
    \item Débranchez les 4 fils du stepper du pont en H L298N.
    \item Desserrez les 4 vis M3 qui fixent le moteur au support.
    \item Retirez le moteur et montez le nouveau en vérifiant l'ordre des bobines (A+, A-, B+, B-).
\end{enumerate}

\subsection{Support inférieur de la sonde}

\begin{figure}[H]
    \centering
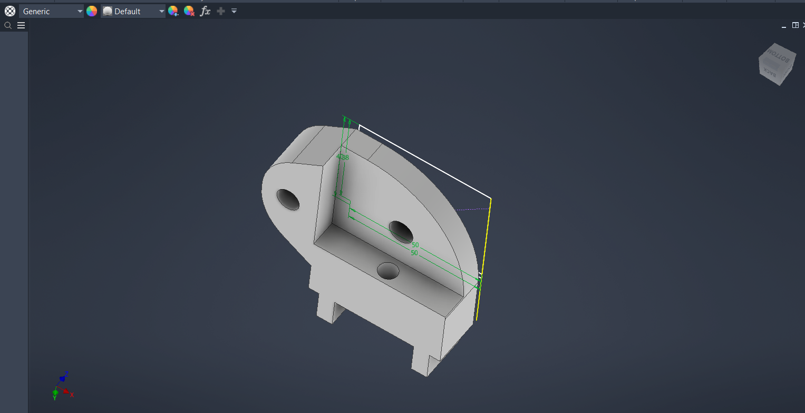
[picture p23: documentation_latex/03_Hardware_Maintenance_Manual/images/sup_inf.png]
    
    \caption{Conception CAO du support inférieur de la sonde.}
    \label{fig:sup_inf}
\end{figure}

\subsection{Support du capteur de sol}

\begin{figure}[H]
    \centering
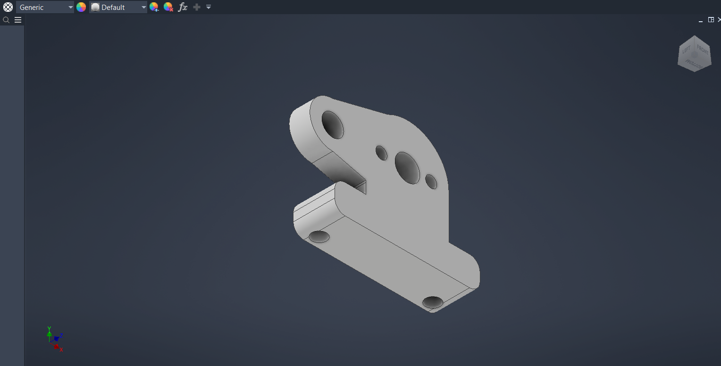
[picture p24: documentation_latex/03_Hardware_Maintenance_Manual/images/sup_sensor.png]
    
    \caption{Conception CAO du support du capteur pédologique.}
    \label{fig:sup_sensor}
\end{figure}

\subsection{Sonde à vis finalisée}

\begin{figure}[H]
    \centering
    
    \caption{Sonde à vis assemblée et prête au montage.}
    \label{fig:sonda}
\end{figure}

La sonde se monte sur le châssis inférieur. La vis pénètre dans le sol lorsque le moteur pas à pas tourne. En cas d'usure de la vis, elle peut être retirée en desserrant le coupleur qui la relie à l'arbre du moteur.

\subsection{Supports des batteries}

\begin{figure}[H]
    \centering
    \begin{minipage}{0.48\textwidth}
        \centering
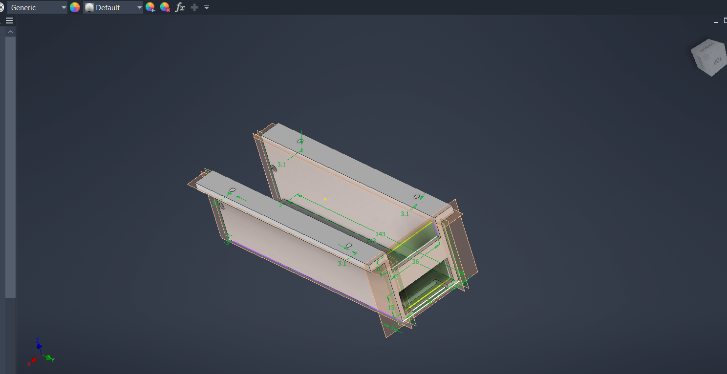
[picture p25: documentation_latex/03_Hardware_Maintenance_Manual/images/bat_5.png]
        
    \end{minipage}
    \hfill
    \begin{minipage}{0.48\textwidth}
        \centering
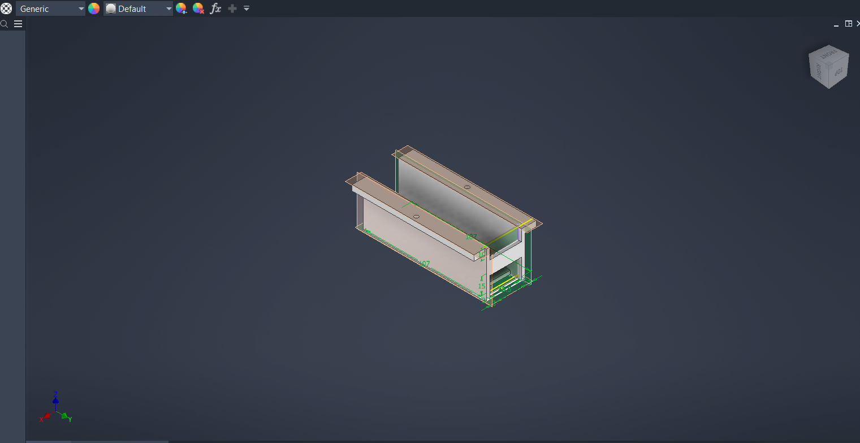
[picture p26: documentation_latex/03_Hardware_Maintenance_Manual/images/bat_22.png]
        
    \end{minipage}
    \caption{Conception CAO des supports des batteries LiPo (5000 mAh à gauche, 2200 mAh à droite).}
    \label{fig:supports_bat}
\end{figure}

Ces supports sont fixés sur la plaque aluminium par des vis M3 et maintiennent les batteries même sur terrain accidenté.

% ============================================================
\section{Débogage Matériel}

\subsection{Roues non contrôlées au démarrage}
Symptôme : les roues tournent de façon erratique ou ne répondent pas aux commandes.

Causes possibles :
\begin{itemize}
    \item GND flottant : absence de masse commune entre le Raspberry Pi, l'Arduino et les ESC. Vérifiez la continuité du fil GND du câble USB (entre Pi et Arduino) et la connexion GND entre l'Arduino et chaque ESC.
    \item ESC non initialisé : les ESC RC doivent recevoir un signal neutre (90°) avant de répondre. Le firmware envoie ce signal au démarrage ; si l'Arduino n'est pas encore prêt, les ESC resteront en veille. Redémarrez le système.
    \item Batterie LiPo 5000 mAh insuffisante : une batterie déchargée peut provoquer un comportement imprévisible. Vérifiez la tension avec un voltmètre (minimum 10,5 V pour un pack 3S).
\end{itemize}

\subsection{LIDAR muet ou absent}
Symptôme : le LIDAR tourne physiquement mais le topic \texttt{/scan} est vide ou absent.

Procédure de diagnostic :
\begin{enumerate}
    \item Vérifiez que le port est correctement assigné :
\begin{verbatim}
ls /dev/ttyUSB*
\end{verbatim}
    \item Vérifiez les permissions :
\begin{verbatim}
sudo chmod 666 /dev/ttyUSB0
\end{verbatim}
    \item Relancez le nœud LIDAR et observez les logs :
\begin{verbatim}
ros2 run rplidar_ros rplidar_composition \
  --ros-args -p serial_port:=/dev/ttyUSB0 \
             -p serial_baudrate:=115200
\end{verbatim}
    \item Si le LIDAR est sur \texttt{/dev/ttyUSB1} (conflit avec le capteur sol), échangez les ports USB ou créez des règles \texttt{udev} permanentes.
\end{enumerate}

\subsection{Arduino non détecté}
Symptôme : le nœud Python affiche \texttt{Serial: No device found} et s'arrête.
\begin{enumerate}
    \item Vérifiez la présence du port :
\begin{verbatim}
ls /dev/ttyACM*
\end{verbatim}
    \item Vérifiez les permissions :
\begin{verbatim}
sudo chmod 666 /dev/ttyACM0
\end{verbatim}
    \item Débranchez et rebranchez le câble USB. Le délai de 2 secondes dans le code permet à l'Arduino de finir son reset.
    \item Si le port reste absent, testez l'Arduino sur un autre PC avec l'IDE Arduino pour confirmer qu'il fonctionne.
\end{enumerate}

\subsection{Sonde ne descend pas}
Symptôme : la commande \texttt{D} est envoyée mais aucun mouvement n'est observé.
\begin{itemize}
    \item Vérifiez que la batterie LiPo 2200 mAh est connectée et chargée.
    \item Vérifiez la LED d'état du pont en H L298N : elle doit être allumée.
    \item Vérifiez les connexions des 4 fils du moteur pas à pas sur les sorties A/B du L298N.
    \item Testez le moteur manuellement avec \texttt{calibrate\_probe.py} (voir User Manual).
\end{itemize}

\subsection{Caméra non détectée}
Symptôme : le nœud \texttt{v4l2\_camera\_node} échoue au démarrage.
\begin{enumerate}
    \item Vérifiez la présence du périphérique :
\begin{verbatim}
ls /dev/video*
v4l2-ctl --list-devices
\end{verbatim}
    \item Débranchez et rebranchez la webcam USB.
    \item Si plusieurs caméras sont présentes, précisez le bon périphérique dans le fichier de lancement (\texttt{video\_device: /dev/video0}).
\end{enumerate}

\subsection{Conflit de ports USB (/dev/ttyUSB0 vs /dev/ttyUSB1)}
Le LIDAR et le capteur NPK utilisent tous deux une connexion USB série. Leur assignation (\texttt{ttyUSB0} ou \texttt{ttyUSB1}) peut varier selon l'ordre de branchement. Pour fixer les ports de manière permanente, créez des règles \texttt{udev} basées sur le numéro de série USB de chaque appareil :
\begin{verbatim}
udevadm info -a -n /dev/ttyUSB0 | grep '{serial}'
\end{verbatim}
Puis créez un fichier \texttt{/etc/udev/rules.d/99-agri.rules} avec les règles appropriées.

% ============================================================
\section{Maintenance Préventive}

\begin{table}[H]
\centering
\begin{tabularx}{\textwidth}{llX}
\toprule
\textbf{Fréquence} & \textbf{Composant} & \textbf{Action} \\
\midrule
Avant chaque mission & Batteries LiPo & Vérifier la tension (min 10,5 V pour 3S). \\
Avant chaque mission & Visserie générale & Vérifier que les vis de fixation ne sont pas desserrées par les vibrations. \\
Avant chaque mission & Sonde à vis & Vérifier que la vis n'est pas obstruée par de la terre. \\
Après chaque mission & Sonde et capteur sol & Nettoyer la vis et le capteur NPK avec une brosse sèche. \\
Toutes les 10 missions & Moteurs de traction & Vérifier l'absence de débris coincés dans les roues. \\
Toutes les 10 missions & Câblage général & Vérifier l'absence de câbles frottés ou déconnectés. \\
En cas de chute & Toutes pièces 3D & Inspecter visuellement les supports pour fissures. Réimprimer si nécessaire. \\
\bottomrule
\end{tabularx}
\caption{Tableau de maintenance préventive.}
\end{table}

\end{document}

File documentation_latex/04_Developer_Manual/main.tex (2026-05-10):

\documentclass [12pt, a4paper]{article}
\usepackage[utf8]{inputenc}
\usepackage[french]{babel}
\usepackage{wrapfig}
\usepackage[pdftex]{color,graphicx}
\usepackage{mathrsfs}
\usepackage[labelformat = empty]{subcaption}
\usepackage[justification=centering]{caption}
\usepackage[]{multirow}
\usepackage{float}
\usepackage{tabularx}
\usepackage{booktabs}
\usepackage[usenames,dvipsnames,svgnames,table]{xcolor}
\usepackage{siunitx}
\usepackage{upquote}
\usepackage{amsmath}
\usepackage{hyperref}
\usepackage{tikz}
\usetikzlibrary{positioning, shapes.geometric, arrows.meta}

% Margens
\usepackage[top=3cm, bottom=3cm, left=3cm, right=3cm]{geometry}
% Fonte
\usepackage[T1]{fontenc}
\usepackage{fancyhdr} 
\pagestyle{fancy}     

\fancyhf{}             
\lhead{UE 4.4 - Projet \hfill \thepage}

\begin{document}

% Capa de apresentação
\input{Capa}

% Sumário
\renewcommand{\contentsname}{\centering Sommaire}
\tableofcontents
\thispagestyle{empty} 
\setcounter{page}{0} 

\newpage
\section{Introduction}
Le Developer Manual décrit l'architecture mécanique, électronique et logicielle complexe du robot.
L'Agri-Scout est propulsé par ROS 2 Jazzy, OpenCV et um pont de communication dynamique avec Arduino.

\section{Architecture Mécanique}
Comme défini dans le Hardware Maintenance Manual, des supports personnalisés ont été conçus à partir de la structure de base du robot pour accueillir les capteurs et l'électronique. Le robot étant destiné à opérer en milieu agricole, il est équipé d'un capteur pour extraire les paramètres du sol. Pour que le capteur puisse fonctionner, il doit pénétrer le terrain ; à cet effet, une sonde à vis a été conçue et couplée au châssis du robot. La sonde est actionnée par un moteur pas à pas NEMA. Compte tenu de la complexité de la conception et de la fabrication de la sonde, la partie mécanique du robot a été divisée en deux parties principales : la conception/fabrication de la sonde et les autres supports du robot.

\subsection{Châssis de base du robot}

La structure de base du robot est présentée dans la figure \ref{fig:chassi}, ainsi que les moteurs et leurs ESC de commande. Chaque roue possède son propre moteur : les moteurs de gauche sont contrôlés par l'un des ESC et les moteurs de droite par l'autre.

\begin{figure}[H]
    \centering
     
    \caption{Châssis de base du robot.}
    \label{fig:chassi} 
\end{figure}

Comme de nombreux composants sont couplés au robot, il a été nécessaire d'ajouter un étage supplémentaire. Une plaque d'aluminium a été choisie pour constituer le second étage du robot, en raison de sa facilité de perçage et de la résistance du matériau. La plaque a été découpée en laboratoire selon les dimensions du châssis. Des supports métalliques ont été utilisés pour fixer la plaque au châssis. La figure \ref{fig:chassi_final} montre le châssis finalisé et prêt à recevoir les composants.

Le châssis est organisé en deux niveaux :
\begin{itemize}
    \item Niveau inférieur (châssis d'origine) : moteurs de traction, ESC, câblage de puissance.
    \item Niveau supérieur (plaque aluminium) : Raspberry Pi, Arduino, pont en H, batteries, capteurs.
\end{itemize}

\begin{figure}[H]
    \centering
     
    \caption{Châssis de base + second étage.}
    \label{fig:chassi_final}
\end{figure}

\subsection{Conception et fabrication de la sonde à vis}
Des matériaux disponibles au laboratoire ont été utilisés pour commencer la production de la sonde. Un moteur pas à pas NEMA, un support pour toute la structure et la vis ont été utilisés. À partir des dimensions fixes de ces composants, le reste de la structure a été conçu. La conception de la sonde à vis a été réalisée à l'aide du logiciel Autodesk Inventor. Après la conception, les fichiers ont été exportés au format STL et envoyés pour l'impression 3D. Les images ci-dessous montrent les supports conçus :

\begin{figure}[H]
    \centering
    \begin{minipage}{0.48\textwidth}
        \centering
        
    \end{minipage}
    \hfill
    \begin{minipage}{0.48\textwidth}
        \centering
        
    \end{minipage}
    \vfill
    \begin{minipage}{0.48\textwidth}
        \centering
        
    \end{minipage}
    \caption{Conception de la sonde à vis.}
    \label{fig:x}
\end{figure}

La figure \ref{fig:sonda} montre la sonde à vis finalisée et prête à être fixée au châssis du robot.

\begin{figure}[H]
      \centering
    
    \caption{Sonde à vis finalisée.}
    \label{fig:sonda}  
\end{figure}

\subsection{Conception et fabrication des autres supports}
Le robot pouvant opérer sur des terrains irréguliers, les batteries doivent être solidement fixées au châssis pour éviter les déconnexions inattendues. Ainsi, deux supports pour chacune des batteries ont été conçus, comme l'indique la figure \ref{fig:suportes_baterias}.

\begin{figure}[H]
    \centering
    \begin{minipage}{0.48\textwidth}
        \centering
        
    \end{minipage}
    \hfill
    \begin{minipage}{0.48\textwidth}
        \centering
        
    \end{minipage}
    \caption{Supports des batteries LiPo.}
    \label{fig:suportes_baterias}
\end{figure}

Un autre support important, destiné à élever le LIDAR, la centrale inertielle et à fournir une finition statique au robot, est présenté dans la figure \ref{fig:suporte_lidar}.

\begin{figure}[H]
    \centering
    
    \caption{Support d'élévation pour le LIDAR et la centrale inertielle.}
    \label{fig:suporte_lidar}
\end{figure}

Un support supplémentaire a été conçu pour se fixer au support de la figure \ref{fig:suporte_lidar}. Ce dernier sert à fixer le LIDAR et la centrale inertielle, tout en permettant la rotation des capteurs pour mieux calibrer et définir les références des deux capteurs.

\begin{figure}[H]
    \centering
    
    \caption{Support de fixation pour le LIDAR et la centrale inertielle.}
    \label{fig:sup_lidar}
\end{figure}

\section{Architecture Électronique}
L'unité centrale de traitement du robot est um Raspberry Pi 4 couplé à un Arduino UNO. L'Arduino est responsable du contrôle des moteurs de toutes les roues, ainsi que du moteur pas à pas de la sonde à vis via le pont en H. L'Arduino garantit que l'envoi des commandes aux moteurs est rapide et efficace, évitant les retards qui pourraient survenir si le Raspberry Pi s'en chargeait. Le Raspberry Pi traite les données des capteurs, tels que la caméra et le LIDAR, et envoie les commandes de mouvement à l'Arduino.

Le Raspberry Pi et l'Arduino ont été fixés sur le châssis supérieur du robot. Le pont en H connecté au moteur pas à pas a été fixé directement à l'Arduino pour faciliter la connexion et éviter l'usage de câbles longs. La figure \ref{fig:eletronica} montre la disposition des composants.

\begin{figure}[H]
    \centering
    
    \caption{Disposition du Raspberry Pi et de l'Arduino.}
    \label{fig:eletronica}
\end{figure}

\subsection{LIDAR RPLiDAR}
Le LIDAR utilisé est un RPLiDAR. Ce capteur effectue un balayage à 360° à l'aide d'un faisceau laser infrarouge, mesurant les distances aux obstacles environnants avec une précision millimétrique. Il est connecté au Raspberry Pi via USB et communique à un débit de 115200 bauds. Dans le système, il est principalement utilisé comme dispositif de sécurité : le nœud ROS 2 surveille en permanence le secteur frontal (±30°) et déclenche un arrêt d'urgence si un obstacle se trouve à moins de 20 cm. Le LIDAR est monté en hauteur sur le support d'élévation imprimé en 3D afin de maximiser son champ de vue.

\begin{figure}[H]
    \centering
    
    \caption{RPLiDAR monté sur le robot.}
    \label{fig:lidar_photo}
\end{figure}

\subsection{Centrale Inertielle (IMU)}
Pour le suivi de l'orientation, nous utilisons la centrale inertielle SparkFun OpenLog Artemis. L'utilisation du Digital Motion Processor (DMP) intégré est
 ici cruciale : il traite les signaux bruts des 9 axes pour générer une estimation d'orientation stable, minimisant ainsi la dérive (drift) du yaw grâce au
référencement magnétique.

La fixation mécanique de l'IMU sur le support rotatif du LIDAR permet une coïncidence parfaite des axes de mesure. En raison de l'utilisation complète des 
interfaces USB de la Raspberry Pi 4, l'intégration système a été optimisée en utilisant la communication UART via les broches GPIO. Ce choix permet de maintenir 
une bande passante dédiée à la télémétrie inertielle sans interférer avec les transferts de données massifs des autres capteurs USB.

\begin{figure}[H]
    \centering
    
    \caption{Module SparkFun OpenLog Artemis fixé sur le support du LIDAR.}
    \label{fig:imu_photo}
\end{figure}

\subsection{Webcam USB}
La webcam est une caméra USB standard, utilisée comme capteur de vision principale du robot. Elle est gérée par le pilote ROS 2 \texttt{v4l2\_camera}, qui publie les images sur le topic \texttt{/image\_raw}. La résolution de capture est configurée à 320×240 pixels en format MJPEG, afin de réduire la charge de traitement sur le Raspberry Pi. Le nœud de contrôle redimensionne ensuite chaque trame à 160×120 pixels pour l'analyse par vision par ordinateur (détection de ligne et de marqueurs de récolte).

\begin{figure}[H]
    \centering
    
    \caption{Webcam USB montée sur le châssis du robot.}
    \label{fig:webcam_photo}
\end{figure}

\subsection{Connexions Arduino et actionneurs}

Il est important de noter que la connexion électrique entre l'Arduino, les ESC et le pont en H peut être vérifiée dans le code du fichier \texttt{main\_firmware.ino}. Après avoir accédé au Raspberry Pi en suivant les instructions du Quick Start Guide, le code est disponible dans le répertoire :
\begin{verbatim}
~/AGRI-Scout_Modif/arduino_firmware/main_firmware/main_firmware.ino
\end{verbatim}
Le diagramme simplifié de la figure \ref{fig:diagram} présente les connexions électriques entre les composants.

\begin{figure}[H]
    \centering
    \begin{tikzpicture}[
        node distance=2cm,
        block/.style={rectangle, draw, fill=blue!10, text width=3.5cm, text centered, minimum height=4cm, font=\bfseries},
        smallblock/.style={rectangle, draw, fill=green!10, text width=2.5cm, text centered, minimum height=1.5cm},
        motor/.style={circle, draw, fill=orange!10, text width=2cm, text centered, minimum size=2cm},
        line/.style={draw, -{Stealth[scale=1.2]}}
    ]

    % --- Blocos Principais ---
    \node [block] (arduino) {Arduino Uno};
    \node [block, right=4cm of arduino] (l298n) {Pont en H};
    \node [block, below left=3cm and 0.15cm of arduino] (ESCs) {ESCs des roues};

    % --- Conexões Arduino -> Ponte H ---
    \draw [line] ([yshift=1.5cm]arduino.east) -- node[above, font=\small] {pin 4} ([yshift=1.5cm]l298n.west) node[right, pos=1, font=\scriptsize] {M1};
    \draw [line] ([yshift=0.5cm]arduino.east) -- node[above, font=\small] {pin 7} ([yshift=0.5cm]l298n.west) node[right, pos=1, font=\scriptsize] {M2};
    \draw [line] ([yshift=-0.5cm]arduino.east) -- node[above, font=\small] {pin 5} ([yshift=-0.5cm]l298n.west) node[right, pos=1, font=\scriptsize] {E1};
    \draw [line] ([yshift=-1.5cm]arduino.east) -- node[above, font=\small] {pin 6} ([yshift=-1.5cm]l298n.west) node[right, pos=1, font=\scriptsize] {E2};

    % --- Motor de Passo ---
    \node [motor, below=2cm of l298n] (stepper) {Moteur pas à pas};
    
    % Conexão Ponte H -> Motor
    \draw [line] (l298n.south) -- (stepper.north) node[midway, right] {Sorties A/B};
    
    % --- Conexões Arduino -> ESCs ---
    \draw [line] ([xshift=-0.5cm]arduino.south) |- node[below, font=\small] {pin 9} (ESCs.north east);
    \draw [line] (arduino.south) |- node[right, font=\small] {pin 10} (ESCs.south east);
    
    % --- Aterramento (GND) ---
    \node [ below right=1.8cm and 0.2cm of arduino] (gnd) {Masse commune (GND)};
    \draw [line] (arduino.south east) -- (gnd.north);
    \draw [line] (l298n.south west) -- (gnd.north);
    \draw [line] (ESCs.north) |- (gnd.west);

    % --- Título do Diagrama ---
    \node [above=0.5cm of arduino, text width=10cm, text centered, font=\Large\bfseries] {Schéma de Câblage};

    \end{tikzpicture}
    
    \caption{Diagramme de connexion électrique.}
    \label{fig:diagram}
\end{figure}

\section{Architecture Logicielle}

Le logiciel du robot est organisé autour d'un nœud ROS 2 central écrit en Python, d'un firmware Arduino et d'un ensemble de scripts utilitaires. Les fichiers sources sont regroupés dans deux répertoires principaux du dépôt :
\begin{itemize}
    \item \texttt{python\_control/} — scripts Python (nœuds ROS 2 et utilitaires autonomes)
    \item \texttt{arduino\_firmware/} — code source Arduino
\end{itemize}

\subsection{Nœud Principal : \texttt{agri\_line\_follower.py}}
Ce nœud agit comme le « cerveau » du robot en mission autonome. Il intègre trois flux asynchrones : la caméra V4L2 (topic \texttt{/image\_raw}),
 le scanner LIDAR (topic \texttt{/scan}) et la liaison USB vers l'Arduino. La machine à états interne comporte deux modes principaux :
\begin{itemize}
    \item FOLLOWING : suivi de ligne blanche par vision, avec un correcteur PD pour le guidage latéral.
    \item HARVESTING : séquence automatique de descente, collecte de données et remontée de la sonde.
\end{itemize}
Afin d'éviter une surcharge du Raspberry Pi, plusieurs contraintes de performance sont appliquées :
\begin{itemize}
    \item OpenCV Mono-Core : \texttt{cv2.setNumThreads(1)} limite l'utilisation à un seul cœur CPU.
    \item Downscaling : l'image est redimensionnée à 160×120 pixels avant traitement.
    \item Throttling : les trames de débogage publiées sur \texttt{/agri\_debug} sont émises à raison d'une trame sur 15.
\end{itemize}
Un watchdog interne surveille la réception des images et ordonne l'arrêt d'urgence si aucune donnée n'est reçue pendant plus de 15 secondes. La récolte périodique automatique est également déclenchée toutes les 30 secondes via un timer ROS 2.

\subsection{Nœud de Démonstration : \texttt{agri\_demo\_hunter.py}}
Ce nœud alternatif a été développé pour les démonstrations. Au lieu de suivre une ligne, il recherche un objet coloré (par défaut rouge/orange) dans le champ de vision de la caméra et s'en approche. Il dispose d'une machine à états similaire (SEARCHING, TRACKING, HARVESTING) et utilise également le LIDAR pour la détection d'obstacles. Il peut être lancé manuellement à la place de \texttt{agri\_line\_follower.py}.

\subsection{Téléopération : \texttt{ros2\_teleop.py}}
Ce nœud permet de contrôler le robot manuellement depuis un terminal via le clavier (touches W/A/S/D pour les déplacements, I/K pour la sonde, Espace pour l'arrêt). Les commandes sont publiées sur le topic ROS 2 \texttt{agri\_commands}. Il est utile pour les phases de test et de réglage.

\subsection{Lecture du Capteur de Sol : \texttt{read\_sensor.py}}
Script autonome (sans ROS 2) qui communique avec le capteur de sol NPK via le protocole Modbus RTU sur le port série \texttt{/dev/ttyUSB1}. Il lit en continu 8 paramètres (température, humidité, conductivité, salinité, azote, phosphore, potassium, pH) et les affiche dans le terminal. À l'arrêt (Ctrl+C), les données de la session sont sauvegardées dans un fichier CSV.

\subsection{Calibration de la Sonde : \texttt{calibrate\_probe.py}}
Utilitaire interactif permettant de calibrer mécaniquement le rail de la sonde. Il envoie des commandes de pas au stepper via la liaison série et affiche la position cumulée (en pas), ce qui permet de déterminer le course maximale sans risque de détériorer la mécanique.

\subsection{Fichiers de Lancement ROS 2}
Deux fichiers de lancement (launch files) orchestrent le démarrage du système :
\begin{itemize}
    \item \texttt{demo.launch.py} — lance simultanément le nœud de caméra V4L2, le nœud LIDAR RPLiDAR et le nœud de suivi de ligne 
    (\texttt{agri\_line\_follower.py}).
    \item \texttt{calibration.launch.py} — lance uniquement le LIDAR et imu\_artemis\_parser.py pour vérifier le fonctionnement.
\end{itemize}

\subsection{Firmware Arduino (\texttt{main\_firmware.ino})}
Dans \texttt{main\_firmware.ino}, l'Arduino agit comme un esclave de bas niveau chargé du contrôle temps réel des actionneurs. Il reçoit des paquets binaires sécurisés (protocole avec octet de début \texttt{0x3C}, commande, valeur, checksum XOR, et octet de fin \texttt{0x3E}) et exécute les actions correspondantes :
\begin{itemize}
    \item \texttt{F} / \texttt{B} : avance / recul
    \item \texttt{L} / \texttt{R} : virage gauche / droite
    \item \texttt{D} / \texttt{U} : descente / remontée de la sonde (stepper)
    \item \texttt{X} : arrêt complet
\end{itemize}
Un mécanisme de watchdog matériel coupe les moteurs si aucune commande n'est reçue pendant plus d'une seconde, garantissant la sécurité en cas de perte de communication. Pour migrer vers une commande différentielle directe et éviter le freinage ABS des ESC RC, le Python envoie désormais des valeurs de vitesse absolues, sans jamais inverser brusquement le sens.

\section{Compilation et Modification}
Pour recompiler le nœud ROS 2 :
\begin{verbatim}
cd ~/AGRI-Scout_Modif
colcon build --packages-select <votre_package>
\end{verbatim}

Pour modifier le code Arduino, utilisez l'IDE Arduino sur le code source dans le dossier \texttt{arduino\_firmware}. Le Raspberry Pi dispose d'arduino-cli installé, ce qui permet la compilation et le téléversement du firmware directement depuis le terminal du Raspberry Pi. Pour faciliter l'opération, le fichier \texttt{record.sh} a été créé ; il permet la compilation et l'envoi en lançant simplement la commande suivante :
\begin{verbatim}
bash record.sh <nom_dossier>
\end{verbatim}

Par exemple, si l'utilisateur modifie le code \texttt{main\_firmware.ino}, la commande sera :
\begin{verbatim}
bash record.sh main_firmware
\end{verbatim}

\end{document}

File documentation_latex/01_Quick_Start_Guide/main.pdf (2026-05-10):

# (UE 4.4 - Projet)

### Agri-Scout : Robot Autonome pour l’Inspection Agricole et l’Analyse des Sols

# Quick Start Guide

ENSTA Campus de Brest
2 Rue François Verny
29200 Brest Cedex 9, France Pedro ALVES DE ARAUJO SILVA pedro.alves@ensta.fr
Luiz Felipe BARROS ALVES
luiz.barros@ensta.fr


## Sommaire

1 Introduction | 1
2 Identification des Composants | 1
3 Prérequis Matériels | 1
4 Procédure de Démarrage | 2

UE 4.4 - Projet | 1

## 1 Introduction

Ce document est le Quick Start Guide. Il contient les étapes essentielles pour assembler, mettre sous tension et démarrer une mission d’inspection autonome avec l’Agri-Scout.

## 2 Identification des Composants

Avant de commencer, familiarisez-vous avec les éléments clés du robot (voir figure
1) :
— Châssis principal : supporte les 4 roues motrices.
— Interrupteur de puissance : situé à l’arrière, il alimente les moteurs.
— Câbles d’alimentation : connecteurs XT60 pour les batteries LiPo.
— Capteurs : RPLiDAR A1 (au sommet), Webcam USB (à l’avant).
— Sonde d’inspection : mécanisme à vis situé à l’avant pour l’échantillonnage du sol.
— Électronique embarquée : Raspberry Pi 4 et Arduino Uno (sous la plaque supérieure).


Figure 1 – Aperçu général du robot Agri-Scout.

## 3 Prérequis Matériels

Pour démarrer le robot, il faut s’assurer d’avoir les éléments suivants :
— 2 Batteries LiPo (pour les moteurs et ponts en H L298N).
— Powerbank USB-C (pour alimenter le Raspberry Pi de manière isolée afin d’éviter les chutes de tension "brown-outs").

## 4 Procédure de Démarrage

### 4.1 Mise sous tension

1. Connectez la Powerbank au Raspberry Pi. Attendez que le système d’exploitation démarre. La Raspberry a été fixée en dessous du châssis supérieur pour bien diviser tous les composants atachés au robot. L’image 2 montre la position du Raspberry Pi.


Figure 2 – Raspberry Pi fixé sous le châssis supérieur et cable USB-C.

2. Insérez la batterie LiPo 5000mAh dans votre support et branchez-la au circuit de puissance des moteurs, ensuite activez l’interrupteur, comme le montrent les images ci-dessous.

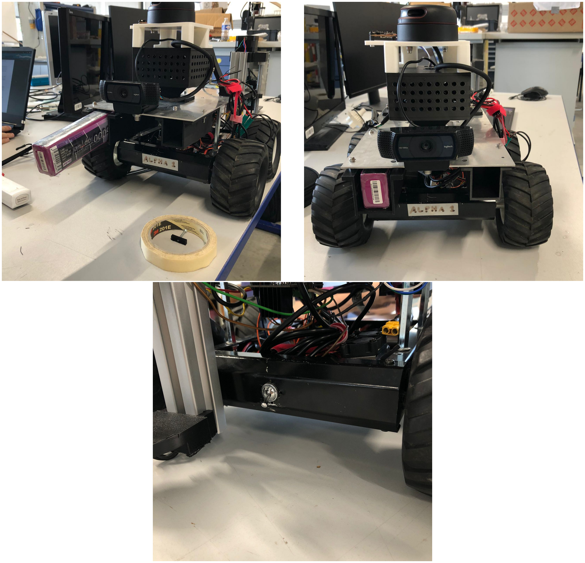
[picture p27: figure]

Figure 3 – Batterie LiPo 5000mAh et interrupteur d’activation.

Assurez-vous que les moteurs réagissent à l’activation de l’alimentation (le bruit des ESC des moteurs est un bon signe).

3. Branchez la batterie LiPo 2200mAh au deuxième câble d’alimentation pour bien activer le moteur pas-à-pas qui est responsable de monter et descendre la sonde à vis.


Figure 4 – Batterie LiPo 2200mAh.

### 4.2 Démarrage Logiciel

Pour se connecter au Raspberry Pi pour la première fois, vous devez utiliser un cable Ethernet pour connecter le Raspberry Pi à votre ordinateur. D’abord, il faut metre en place des configurations sur votre ordinateur. Les instructions suivantes sont pour les systèmes Linux. Comme en general, la langua de configuration est en anglais, les instructions sont écrites en anglais pour éviter les confusions.
1. Open Settings → Network ;
2. Locate the Wired connection ;
3. Open the IPv4 tab ;
4. Change Method from Automatic (DHCP) to Shared to other computers ;
5. Click Apply ;
6. Disable and re-enable the wired connection to restart the interface.
Avec cette configuration, votre ordinateur agira comme un serveur DHCP pour le Raspberry Pi, lui attribuant une adresse IP automatiquement.
La deuxième étape est de se connecter au Raspberry Pi en utilisant SSH. Ouvrez un terminal et tapez la commande suivante :

arp -a

Cette commande affichera une liste des appareils connectés à votre réseau local. Trouvez l’adresse IP associée au Raspberry Pi, généralement 10.42.0.x, et connectezvous en utilisant la commande SSH suivante :

ssh ubuntu@10.42.0.x

Le mot de passe est : agribot.
Une connexion sans fil est également possible si le Raspberry Pi est configuré au préalable pour rejoindre un réseau Wi-Fi local.
Une fois connecté en SSH au Raspberry Pi, exécutez le script d’initialisation principal :

source /opt/ros/jazzy/setup.bash

cd ~/AGRI-Scout_Modif

source install/setup.bash

ros2 launch ~/AGRI-Scout_Modif/demo.launch.py

Ce fichier se charge de lancer :
— Le nœud de la caméra (V4L2).
— Le nœud du RPLiDAR.
— Le contrôleur de vision et de mouvement Python (agri_line_follower.py).

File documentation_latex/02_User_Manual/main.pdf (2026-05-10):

# (UE 4.4 - Projet)

### Agri-Scout : Robot Autonome pour l’Inspection Agricole et l’Analyse des Sols

# User Manual

ENSTA Campus de Brest
2 Rue François Verny
29200 Brest Cedex 9, France Pedro ALVES DE ARAUJO SILVA pedro.alves@ensta.fr
Luiz Felipe BARROS ALVES
luiz.barros@ensta.fr


## Sommaire

1 Introduction | 1
2 Modes d’Utilisation | 1
3 Mode 1 : Mission Autonome | 1
4 Mode 2 : Téléopération Manuelle | 3
5 Mode 3 : Démonstration (Hunter) | 4

6 Acquisition de Données Pédologiques | 5
7 Surveillance à Distance (RQT Image View) | 6
8 Calibration Mécanique de la Sonde | 6
9 Consignes de Sécurité | 7
10 Résolution de Problèmes Courants | 7

UE 4.4 - Projet | 1

## 1 Introduction

Ce User Manual décrit en détail toutes les utilisations supportées par l’Agri-Scout dans des conditions nominales de fonctionnement. Il s’adresse à l’opérateur final souhaitant comprendre et exploiter l’ensemble des fonctionnalités du robot : mission autonome, téléopération manuelle, acquisition de données pédologiques et surveillance à distance.
L’Agri-Scout est un robot agricole différentiel à quatre roues, équipé d’une caméra USB, d’un LIDAR RPLiDAR A1 et d’une sonde à vis motorisée pour l’analyse du sol. Il est piloté par un Raspberry Pi 4 sous ROS 2 Jazzy, communicant avec un Arduino UNO pour le contrôle des actionneurs.
Avant toute utilisation, l’opérateur doit s’assurer que le robot a été correctement mis sous tension en suivant le Quick Start Guide.

## 2 Modes d’Utilisation

L’Agri-Scout supporte trois modes d’utilisation principaux, sélectionnables selon le scénario opérationnel :

Mode | Description
Mission Autonome | Suivi de ligne + récolte automatique. Mode de travail
| principal.
Téléopération | Contrôle manuel du robot depuis un terminal distant
| via SSH.
Démonstration (Hunter) Le robot localise et s’approche d’un objet coloré (dra-
| peau/token).

Table 1 – Modes d’utilisation de l’Agri-Scout.

## 3 Mode 1 : Mission Autonome

### 3.1 Description générale

Dans ce mode, le robot navigue de façon entièrement autonome le long d’une piste balisée par une ligne blanche tracée au sol. À intervalles réguliers (toutes les 30 secondes), ou lorsqu’il détecte un marqueur de récolte rouge, il s’arrête, déploie sa sonde dans le sol pour collecter des données pédologiques, puis reprend sa trajectoire.

### 3.2 Lancement de la mission

Après connexion SSH au Raspberry Pi (voir Quick Start Guide), exécutez la séquence suivante :

source /opt/ros/jazzy/setup.bash
cd ~/AGRI-Scout_Modif

source install/setup.bash
ros2 launch ~/AGRI-Scout_Modif/demo.launch.py

Ce fichier de lancement démarre simultanément :
— Le nœud de la caméra (v4l2_camera_node) sur le topic /image_raw.
— Le nœud du LIDAR RPLiDAR (rplidar_composition) sur le topic /scan. — Le nœud de contrôle principal (agri_line_follower.py).

### 3.3 Suivi de ligne

Le robot identifie la piste blanche à l’aide de sa caméra pointée vers le sol. Un algorithme de segmentation HSV isole les pixels blancs dans une zone d’intérêt (50% inférieur de l’image). Un correcteur PD calcule l’erreur de position latérale du centroïde de la ligne par rapport au centre de l’image et ajuste la différence de vitesse entre les roues gauche et droite pour corriger la trajectoire.
Les seuils HSV par défaut pour la ligne blanche sont :
Canal | Min Max
H (Teinte) | 0 | 255
S (Saturation) | 0 | 60
V (Valeur) | 160 | 255

Table 2 – Seuils HSV de détection de la ligne blanche.

### 3.4 Détection d’obstacles (LIDAR)

En permanence, le nœud surveille les mesures du LIDAR dans un secteur de ±30 centré sur l’avant du robot. Si un obstacle est détecté à moins de 20 cm, le robot s’arrête automatiquement et attend que la voie soit dégagée avant de reprendre.

### 3.5 Déclenchement de la récolte

La séquence de récolte peut être déclenchée de deux façons :

1. Par minuterie automatique : toutes les 30 secondes d’opération en mode FOL-LOWING, le robot lance automatiquement une récolte, quelle que soit sa position.
2. Par marqueur visuel : lorsque la caméra détecte une zone rouge (seuil HSV H : 0–10, S : 120–255, V : 70–255) dont l’aire dépasse le seuil configuré (500 pixels par défaut), le robot lance la séquence de récolte.

### 3.6 Séquence de récolte

1. Arrêt complet des moteurs de traction (CMD X).
2. Descente de la sonde : le moteur pas à pas tourne pendant 15,5 secondes pour enfoncer la sonde dans le sol (CMD D).

3. Collecte de données : le robot reste immobile pendant 10 secondes. Durant cette phase, le capteur NPK (si connecté) peut enregistrer les paramètres du sol.
4. Remontée de la sonde : le moteur pas à pas remonte la sonde pendant 15,5 secondes (CMD U).
5. Avance de dégagement : le robot avance à vitesse réduite pendant 4 secondes pour quitter la zone de récolte et retrouver la ligne (CMD F 20).
6. Retour au mode FOLLOWING.

La durée totale d’une séquence de récolte est d’environ 45 secondes.

### 3.7 Arrêt de la mission

Pour arrêter proprement la mission, appuyez sur Ctrl+C dans le terminal SSH. Le nœud envoie automatiquement une commande d’arrêt (CMD X) à l’Arduino avant de se terminer. L’Arduino dispose également d’un watchdog interne : si aucune commande n’est reçue pendant plus d’une seconde, les moteurs sont coupés automatiquement.

## 4 Mode 2 : Téléopération Manuelle

### 4.1 Description

Ce mode permet à l’opérateur de contrôler le robot directement depuis un terminal, sans logique autonome. Il est utile pour les déplacements de positionnement, les tests de mobilité ou la calibration mécanique.

### 4.2 Lancement

Dans un terminal SSH, exécutez :

source /opt/ros/jazzy/setup.bash
cd ~/AGRI-Scout_Modif
source install/setup.bash
python3 python_control/ros2_teleop.py

### 4.3 Commandes clavier

Touche Action

W | Avancer
S | Reculer
A | Tourner à gauche
D | Tourner à droite
ESPACE | Arrêt complet
I | Descendre la sonde (continu)
K | Monter la sonde (continu)
Q | Quitter et arrêter le robot

Table 3 – Mappage clavier de la téléopération.

Note : Les commandes sont publiées sur le topic ROS 2 agri_commands. Le nœud ros2_serial_bridge.py doit être actif pour relayer ces commandes vers l’Arduino. En pratique, il est conseillé d’utiliser la téléopération conjointement avec le LIDAR actif pour bénéficier de la protection anti-collision.

## 5 Mode 3 : Démonstration (Hunter)

### 5.1 Description

Le mode Démonstration remplace l’algorithme de suivi de ligne par un algorithme de recherche et d’approche d’un objet coloré (drapeau, cône ou token placé sur le terrain). C’est le mode recommandé pour les présentations où un parcours de ligne n’est pas disponible.

### 5.2 Lancement

Arrêtez tout nœud actif (Ctrl+C), puis lancez uniquement la caméra, le LIDAR et le nœud hunter :

source /opt/ros/jazzy/setup.bash
cd ~/AGRI-Scout_Modif
source install/setup.bash
python3 python_control/agri_demo_hunter.py

Note : Le nœud de la caméra et le nœud du LIDAR doivent être lancés séparément ou via un fichier de lancement adapté.

### 5.3 Comportement

1. SEARCHING : le robot tourne lentement sur lui-même à la recherche d’un objet rouge/orange dans son champ de vision.

2. TRACKING : dès que l’objet est détecté, le robot s’aligne et avance vers lui. Un contrôleur proportionnel corrige la trajectoire latéralement.
3. HARVESTING : lorsque l’objet occupe une surface suffisante dans l’image (seuil : 15 000 pixels à résolution 320×240), le robot s’arrête et lance la séquence de récolte.

La couleur cible par défaut (rouge/orange) peut être ajustée dans le fichier agri_demo_hunter.py en modifiant les variables lower_color et upper_color (format HSV NumPy).

## 6 Acquisition de Données Pédologiques

### 6.1 Description

Le capteur de sol NPK (connecté sur /dev/ttyUSB1) mesure 8 paramètres en continu via le protocole Modbus RTU. Ce script s’exécute indépendamment de ROS 2 et peut être lancé en parallèle d’une mission autonome ou manuellement lors d’une inspection statique.

### 6.2 Lancement

python3 python_control/read_sensor.py

### 6.3 Paramètres mesurés

Paramètre | Unité
Température du sol | °C
Humidité du sol | %
Conductivité électrique µS/cm
Salinité | mg/L
Azote (N) | mg/kg
Phosphore (P) | mg/kg
Potassium (K) | mg/kg
pH | —

Table 4 – Paramètres pédologiques mesurés par le capteur NPK.

Les données sont affichées en temps réel dans le terminal. À l’arrêt (Ctrl+C), elles sont automatiquement sauvegardées dans un fichier sensor_data_log_corrigido.csv dans le répertoire courant.

## 7 Surveillance à Distance (RQT Image View)

### 7.1 Description

L’opérateur peut visualiser le flux vidéo traité par l’algorithme OpenCV depuis un PC connecté au même réseau que le Raspberry Pi. Ce flux indique en temps réel les contours détectés, le centroïde de la ligne et l’état du robot.

### 7.2 Configuration réseau

Assurez-vous que les deux machines partagent le même ROS_DOMAIN_ID :

export ROS_DOMAIN_ID=0
export ROS_LOCALHOST_ONLY=0

### 7.3 Lancement sur le PC de l’opérateur

source /opt/ros/jazzy/setup.bash
ros2 run rqt_image_view rqt_image_view

Sélectionnez le topic /agri_debug dans le menu déroulant pour visualiser l’image annotée. Le flux est émis à un rythme réduit (1 trame sur 15) pour économiser la bande passante Wi-Fi.

## 8 Calibration Mécanique de la Sonde

### 8.1 Description

Avant la première utilisation, ou après démontage mécanique, il est nécessaire de calibrer la course maximale de la sonde à vis pour éviter de détériorer la mécanique.

### 8.2 Procédure

1. Suspendez le robot ou placez-le sur une surface sans obstacles sous la sonde.
2. Connectez-vous en SSH au Raspberry Pi.
3. Lancez le script de calibration :

python3 python_control/calibrate_probe.py

4. Entrez un nombre de pas positif (ex. 50) pour descendre la sonde, ou négatif (ex. -50) pour la remonter.
5. Notez la valeur affichée comme « distance relative comptée » lorsque la sonde atteint sa butée inférieure. Cette valeur correspond au nombre de pas total du course mécanique.
6. Appuyez sur Ctrl+C ou entrez 0 pour quitter.
Utilisez de petites valeurs (10 à 20 pas) lorsque vous approchez de la butée mécanique pour éviter de forcer le moteur.

## 9 Consignes de Sécurité

— Ne jamais lancer le robot en espace confiné sans vérifier que le LIDAR est actif et fonctionnel.
— Toujours couper l’alimentation des batteries LiPo après utilisation pour éviter la décharge profonde.
— Ne pas approcher les mains du mécanisme de la sonde lorsqu’une séquence de récolte est en cours.
— En cas de comportement anormal, couper l’interrupteur de la batterie moteur immédiatement. Le Watchdog Arduino arrêtera les moteurs dans la seconde. — Ne pas exposer les batteries LiPo à une chaleur excessive ou à des chocs mécaniques.

## 10 Résolution de Problèmes Courants

Symptôme | Solution
Le robot ne démarre pas sa mission | Vérifiez que l’Arduino est connecté via USB et que le port /dev/ttyACM0 est ac- cessible. Consultez les logs du nœud.
Le robot ne suit pas la ligne | Vérifiez l’éclairage ambiant. Ajustez les seuils HSV (line_v_lo) dans le lance- ment ROS 2.

Arrêt intempestif à chaque démarrage Le LIDAR détecte un obstacle. Vérifiez
| que la zone frontale est dégagée sur au moins 20 cm.
La sonde ne descend pas | Vérifiez que la batterie LiPo 2200mAh est branchée et que le pont en H L298N est actif (LED allumée).
Pas d’image sur /agri_debug | Vérifiez que le ROS_DOMAIN_ID est iden- tique sur le Pi et sur le PC.
Erreur Serial: No device | L’Arduino n’est pas détecté. Recon- nectez le câble USB. Vérifiez avec ls /dev/ttyACM*.

Table 5 – Problèmes courants et solutions.

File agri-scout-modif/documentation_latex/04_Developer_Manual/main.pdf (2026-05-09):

# (UE 4.4 - Projet)

### Agri-Scout : Robot Autonome pour l’Inspection Agricole et l’Analyse des Sols

# Developer Manual

ENSTA Campus de Brest
2 Rue François Verny
29200 Brest Cedex 9, France Pedro ALVES DE ARAUJO SILVA pedro.alves@ensta.fr
Luiz Felipe BARROS ALVES
luiz.barros@ensta.fr


## Sommaire

1 Introduction | 1
2 Architecture Mécanique | 1
3 Architecture Électronique | 4
4 Architecture Logicielle | 5
5 Compilation et Modification | 6

UE 3.4 - Projet | 1

## 1 Introduction

Le Developer Manual décrit l’architecture mécanique, électronique et logicielle complexe du robot. L’Agri-Scout est propulsé par ROS 2 Jazzy, OpenCV et um pont de communication dynamique avec Arduino.

## 2 Architecture Mécanique

Comme défini dans le Hardware Maintenance Manual, des supports personnalisés ont été conçus à partir de la structure de base du robot pour accueillir les capteurs et l’électronique. Le robot étant destiné à opérer en milieu agricole, il est équipé d’un capteur pour extraire les paramètres du sol. Pour que le capteur puisse fonctionner, il doit pénétrer le terrain ; à cet effet, une sonde à vis a été conçue et couplée au châssis du robot. La sonde est actionnée par un moteur pas à pas NEMA. Compte tenu de la complexité de la conception et de la fabrication de la sonde, la partie mécanique du robot a été divisée en deux parties principales : la conception/fabrication de la sonde et les autres supports du robot.

### 2.1 Châssis de base du robot

La structure de base du robot est présentée dans la figure 1, ainsi que les moteurs et leurs ESC de commande. Chaque roue possède son propre moteur : les moteurs de gauche sont contrôlés par l’un des ESC et les moteurs de droite par l’autre.

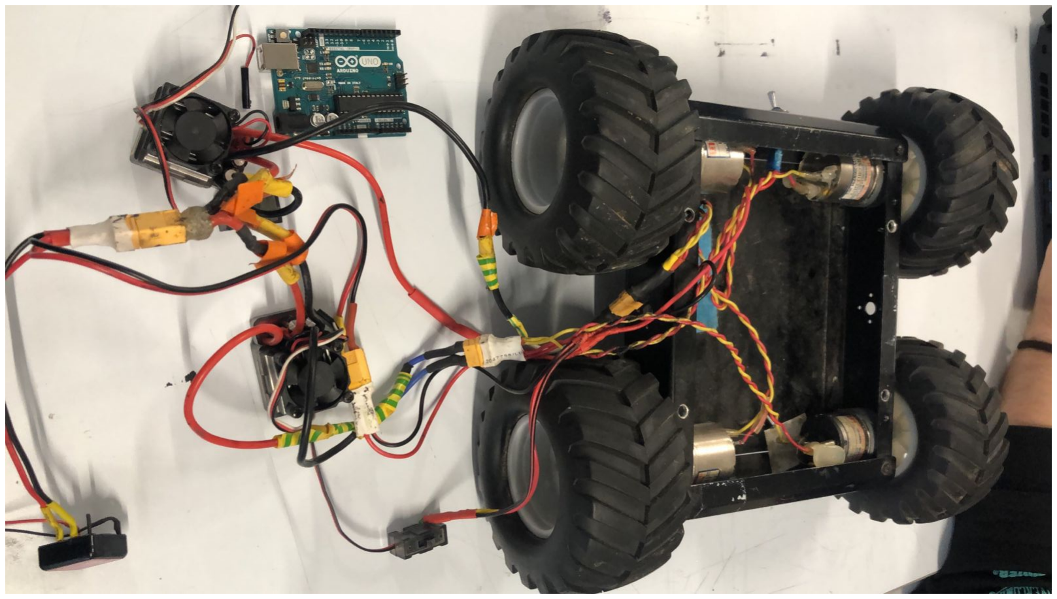
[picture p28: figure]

Figure 1 – Châssis de base du robot.

Comme de nombreux composants sont couplés au robot, il a été nécessaire d’ajouter un étage supplémentaire. Une plaque d’aluminium a été choisie pour constituer le second étage du robot, en raison de sa facilité de perçage et de la résistance du matériau. La plaque a été découpée en laboratoire selon les dimensions du châssis. Des supports métalliques ont été utilisés pour fixer la plaque au châssis. La figure 2 montre le châssis finalisé et prêt à recevoir les composants.


Figure 2 – Châssis de base + second étage.

### 2.2 Conception et fabrication de la sonde à vis

Des matériaux disponibles au laboratoire ont été utilisés pour commencer la production de la sonde. Un moteur pas à pas NEMA, un support pour toute la structure et la vis ont été utilisés. À partir des dimensions fixes de ces composants, le reste de la structure a été conçu. La conception de la sonde à vis a été réalisée à l’aide du logiciel Autodesk Inventor. Après la conception, les fichiers ont été exportés au format STL et envoyés pour l’impression 3D. Les images ci-dessous montrent les supports conçus :

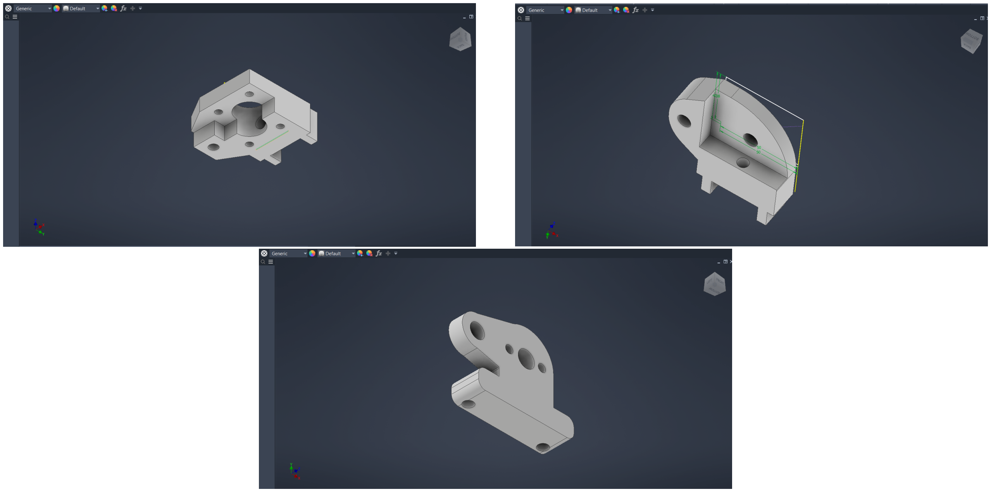
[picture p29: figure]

Figure 3 – Conception de la sonde à vis.

La figure 4 montre la sonde à vis finalisée et prête à être fixée au châssis du robot.


Figure 4 – Sonde à vis finalisée.

### 2.3 Conception et fabrication des autres supports

Le robot pouvant opérer sur des terrains irréguliers, les batteries doivent être solidement fixées au châssis pour éviter les déconnexions inattendues. Ainsi, deux supports pour chacune des batteries ont été conçus, comme l’indique la figure 5.

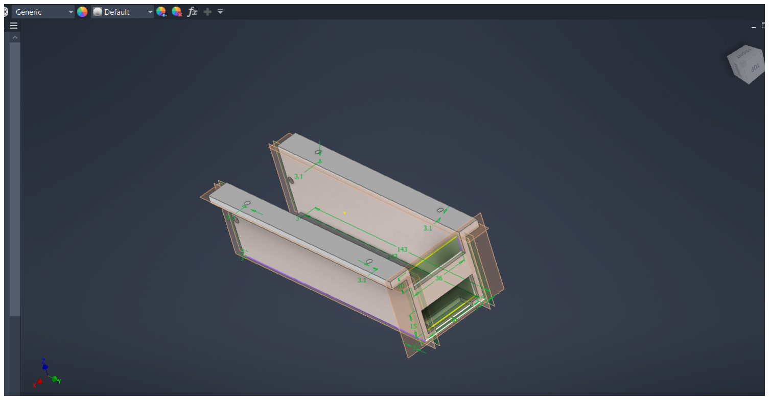
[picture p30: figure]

Figure 5 – Supports des batteries LiPo.

Un autre support important, destiné à élever le LIDAR, la centrale inertielle et à fournir une finition statique au robot, est présenté dans la figure 6.


Figure 6 – Support d’élévation pour le LIDAR et la centrale inertielle.

Un support supplémentaire a été conçu pour se fixer au support de la figure 6. Ce dernier sert à fixer le LIDAR et la centrale inertielle, tout en permettant la rotation des capteurs pour mieux calibrer et définir les références des deux capteurs.


Figure 7 – Support de fixation pour le LIDAR et la centrale inertielle.

## 3 Architecture Électronique

L’unité centrale de traitement du robot est um Raspberry Pi 4 couplé à un Arduino UNO. L’Arduino est responsable du contrôle des moteurs de toutes les roues, ainsi que du moteur pas à pas de la sonde à vis via le pont en H. L’Arduino garantit que l’envoi des commandes aux moteurs est rapide et efficace, évitant les retards qui pourraient survenir si le Raspberry Pi s’en chargeait. Le Raspberry Pi traite les données des capteurs, tels que la caméra et le LIDAR, et envoie les commandes de mouvement à l’Arduino.
Le Raspberry Pi et l’Arduino ont été fixés sur le châssis supérieur du robot. Le pont en H connecté au moteur pas à pas a été fixé directement à l’Arduino pour faciliter la connexion et éviter l’usage de câbles longs. La figure 8 montre la disposition des composants.

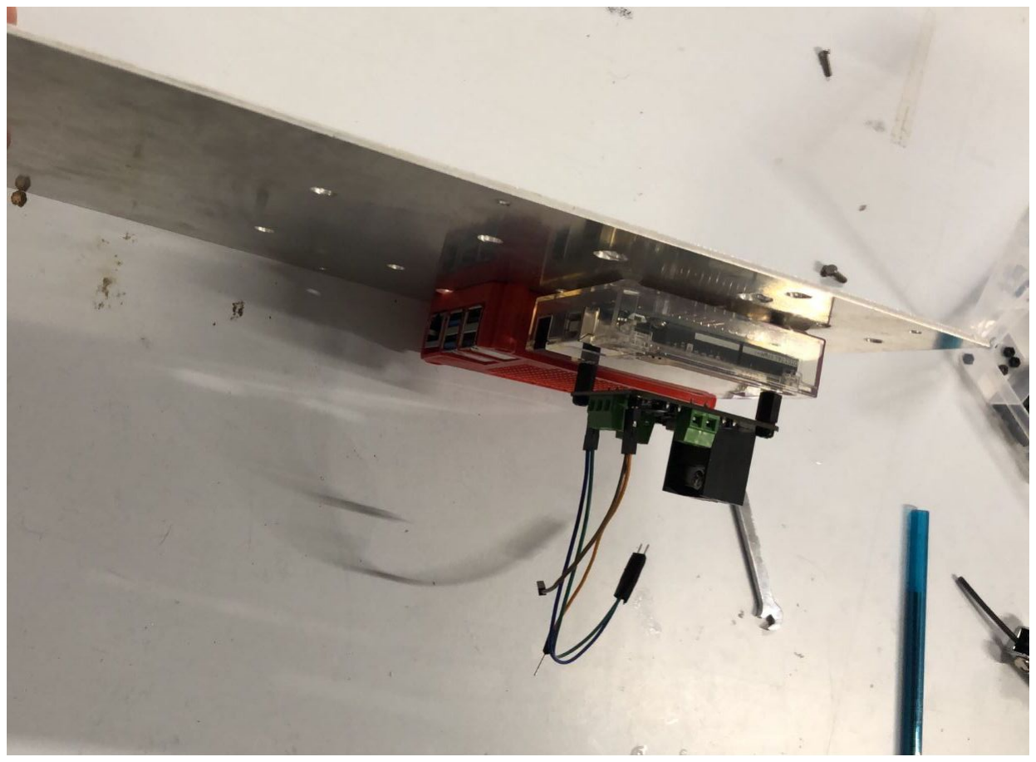
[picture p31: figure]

Figure 8 – Disposition du Raspberry Pi et de l’Arduino.

Il est important de noter que la connexion électrique entre l’Arduino, os ESC et le pont en H peut être vérifiée dans le code du fichier main_firmware.ino. Après avoir accédé au Raspberry Pi en suivant les instructions du Quick Start Guide, le code est disponible dans le répertoire :

~/AGRI-Scout_Modif/arduino_firmware/main_firmware/main_firmware.ino

Le diagramme simplifié de la figure 9 présente les connexions électriques entre les composants.

## 4 Architecture Logicielle

### 4.1 Le Nœud de Traitement Python (agri_line_follower.py)

Ce nœud agit comme le "Cerveau" du robot. Il intègre trois flux asynchrones : la caméra V4L2, le scanner LaserScan du RPLiDAR, et le port Série (UART) de l’Arduino. Afin d’éviter une surcharge de courant (Brown-out) sur le Raspberry Pi, nous avons imposé plusieurs verrous de performance :
— OpenCV Mono-Core : cv2.setNumThreads(1) force l’algorithme à n’utiliser qu’un seul cœur CPU.
— Downscaling Extrême : L’image native est écrasée à 160x120 pixels, réduisant considérablement la charge mathématique des algorithmes de détection. — Network Throttling : Les trames envoyées au PC de débogage (/agri_debug) sont sautées (1 trame sur 15).

### 4.2 Le Firmware Arduino (Protocol M)

Dans main_firmware.ino, l’Arduino agit comme un esclave "Raw PWM". Auparavant, le pilotage "Skid-Steer" entraînait un problème critique avec les ESC RC

## Schéma de Câblage

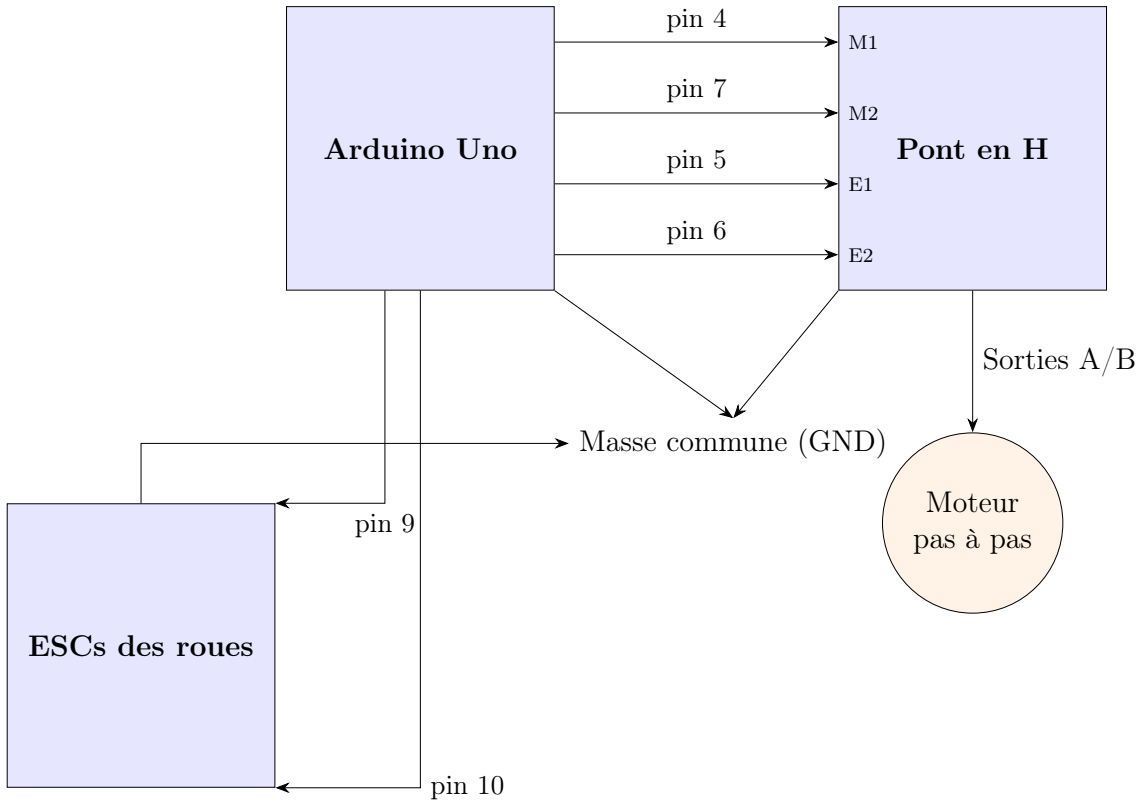
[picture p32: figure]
Arduino Uno; Pont en H; ESCs des roues; pin 4; pin 7; pin 5; pin 6; Moteur pas à pas; Sorties A/B; pin 9; pin 10; Masse commune (GND)

Figure 9 – Diagramme de connexion électrique.

standard : envoyer un ordre de marche arrière sur une roue en marche avant engageait le mode "Freinage ABS", bloquant physiquement le robot.
Nous avons migré vers une architecture de Commande Différentielle Absolue (Commande M <PwmGauche> <PwmDroit>). Le Python envoie désormais les vecteurs de propulsion exacts, évitant de franchir le point mort et neutralisant le freinage indésirable.

Figure 10 – Architecture logicielle ROS 2 et Arduino (Insérer rqt_graph ici).

## 5 Compilation et Modification

Pour recompiler le nœud ROS 2 :

cd ~/AGRI-Scout_Modif
colcon build --packages-select <votre_package>

Pour modifier le code Arduino, utilisez l’IDE Arduino sur le code source dans le dossier arduino_firmware. Le Raspberry Pi dispose d’arduino-cli installé, ce qui permet la compilation et le téléversement du firmware directement depuis le terminal du Raspberry Pi. Pour faciliter l’opération, le fichier record.sh a été créé ; il permet la compilation et l’envoi en lançant simplement la commande suivante :

bash record.sh <nom_dossier>

Par exemple, si l’utilisateur modifie le code main_firmware.ino, la commande sera :

bash record.sh main_firmware

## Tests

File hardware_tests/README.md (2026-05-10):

# Hardware Tests - AGRI-Scout (Physical Robot)

Welcome to the testing toolkit for the physical AGRI-Scout.
These scripts are designed to independently verify each sensor, motor, and the system running ROS 2 (Raspberry Pi 4 B + Arduino), ensuring everything is ready before bringing up the autonomous navigation stack (`nav2`).

This step-by-step guide is designed to walk you through everything from connecting to the internet to running the tests. Follow the steps chronologically.

---

## Step 0: Basic Access and Internet on the Raspberry Pi

If you have powered on the Raspberry Pi and are unsure if it is connected to the internet:

### 1. Connecting the Raspberry Pi to the Internet (Wi-Fi)
If using the Raspberry Pi with a monitor and keyboard, you can connect to Wi-Fi using the OS graphical interface (top right corner).

If accessing via command line (terminal, SSH, or TTY), use the `nmcli` network manager:
```bash
# List available Wi-Fi networks
nmcli dev wifi list

# Connect to your network (replace with your network name and password)
sudo nmcli dev wifi connect "NETWORK_NAME" password "YOUR_WIFI_PASSWORD"
```

### 2. Testing the connection
```bash
ping -c 4 google.com
```
*If the command replies with "64 bytes from...", you have internet access and can proceed! If you get a network error, repeat Step 1.*

---

## Step 1: Verifying and Preparing the Environment (ROS 2)

The robot's brain uses **ROS 2 Jazzy**. We must ensure it is installed and the project workspace (`agri_scout_ws` directory) is ready.

### 1. Is ROS 2 installed?
To check if ROS 2 is installed, try to "source" its environment in the current terminal:
```bash
source /opt/ros/jazzy/setup.bash
```
* **If NOTHING appears on the screen:** The command succeeded, ROS 2 is installed!
* **If you get an error (e.g., `No such file or directory`):** ROS 2 is not installed. Follow the [official ROS 2 Jazzy Ubuntu installation documentation](https://docs.ros.org/en/jazzy/Installation/Ubuntu-Install-Debs.html) (download the "Desktop" packages) before proceeding.

### 2. Does the Workspace (`agri_scout_ws`) exist and is it compiled?
The robot's navigation code and packages are located in the `~/agri_scout_ws` workspace.
Check if it has been compiled and is ready for use by listing the install directory:
```bash
ls ~/agri_scout_ws/install
```
* **If the folder exists:** Great! Source the workspace setup:
  ```bash
  source ~/agri_scout_ws/install/setup.bash
  ```
* **If it DOES NOT exist or you get an error:** You need to compile the entire project. Run the following commands:
  ```bash
  cd ~/agri_scout_ws
  colcon build --symlink-install
  source install/setup.bash
  ```

### 3. Installing Python test dependencies
The test scripts you will run depend on some Python libraries, specifically the `psutil` tool to read CPU and Memory data from the Raspberry Pi.
Install it using the system package manager (recommended for Ubuntu 24.04+):
```bash
sudo apt update
sudo apt install python3-psutil
```

---

## Step 2: Starting Hardware Drivers (The Foundation)

⚠️ **VERY IMPORTANT:** The interactive test scripts (Step 3) **WILL NOT WORK** if the sensors are not logically connected. ROS 2 needs to be "awake" and translating the electrical signal from each USB cable into messages our scripts understand.

To stay organized, open **new terminal tabs** (using the terminal icon or screen/tmux) for each of the drivers below.

In **every new terminal/tab**, you **MUST** always run these two commands first:
```bash
source /opt/ros/jazzy/setup.bash
source ~/agri_scout_ws/install/setup.bash
```

### Terminal A (Arduino - Motors, Encoders, Ultrasound)
Ensure the Arduino is connected via USB and start the micro-ROS agent (if using micro-ROS) or rosserial. Usually, the port is `ttyUSB0`.
```bash
ros2 run micro_ros_agent micro_ros_agent serial --dev /dev/ttyUSB0
# Tip: If it fails saying the port does not exist, disconnect and reconnect the Arduino 
# and run 'dmesg | grep tty' to see the correct name (e.g., ttyACM0).
```

### Terminal B (LiDAR - Laser Scanning Sensor)
Initialize the official LiDAR package. Adjust the launch file name (.py) if using a different model.
```bash
ros2 launch rplidar_ros rplidar_a2m12_launch.py
```

### Terminal C (RealSense Camera - Computer Vision)
Initialize the package that translates the USB image into a ROS image.
```bash
ros2 launch realsense2_camera rs_launch.py
```

**🤔 How to be sure it worked?**
Open any terminal, source the setup (`source /opt/ros/jazzy/setup.bash`) and run:
```bash
ros2 topic list
```
You should see a large list of words like `/scan`, `/odom`, `/camera/color/image_raw`. If they appear, congratulations! The sensors are communicating properly.

---

## Step 3: Running the Practical Hardware Tests

Finally, with the base system publishing data into the robot's veins, let's run the test scripts.
Return to the root of this README:
```bash
cd ~/AGRI-Scout/hardware_tests/
```

Give execution permissions to all scripts (only needs to be done once):
```bash
chmod +x *.py
```

And run them one by one in the suggested order:

### 1. System Monitor (Operation Heart)
```bash
./system_monitor.py
```
* **🔍 What to verify:** CPU usage is acceptable (under 80%), Temperature is not exceeding 75-80°C (preventing chip damage), and RAM is not maxed out (100% usage).

### 2. LiDAR and Camera (High-Throughput Sensors)
These sensors push the most data through the USB cable.
```bash
./test_lidar.py
./test_camera.py
```
* **🔍 What to verify:** Is the publishing frequency (Hz) fast and consistent? Does the LiDAR have points in the scan cloud? Does the Camera open and return at least the frame format (e.g., 640x480)?

### 3. IMU and GPS (Spatial Positioning Sensors)
```bash
./test_imu_gps.py
```
* **🔍 What to verify:** The X, Y, Z orientation from the IMU doesn't spin wildly when the robot is perfectly still on the ground. The GPS gets a satellite signal (valid Fix Status) outdoors.

### 4. Ultrasonic Sensors (Front and Side Bumpers)
```bash
./test_ultrasound.py
```
* **🔍 What to verify:** Place your hand in front of each sensor and observe in the terminal if the displayed distance drops correctly and tracks the real distance of your hand.

### 5. Motors (Odometry and Actuation) ✨ HIGH RISK ✨
⚠️ **RECOMMENDED:** Lift the robot's wheels and place it on a firm stool/block for your first attempt to prevent the robot from shooting forward and hitting someone.
```bash
./test_motors.py
```
* **🔍 What to verify:** 
  1. When pressing `W`, do both tracks/wheels move forward?
  2. Does the odometry value increase consistently?
  3. Press `A` (turn left) and `D` (turn right) - does it turn the correct way?
  4. Press and hold `SPACE` to ensure the instant brake works.

---
**🛠️ Pro Tip / General Troubleshooting:**
If you start any test from **Step 3** and see something like *"Waiting for data..."* permanently in the terminal (for over 10 seconds) and nothing else happens: **Your driver crashed.**
This means Step 2 failed somehow. Return to that driver's terminal, press `Ctrl+C` to kill the process, check the USB cable connections, and start it again.

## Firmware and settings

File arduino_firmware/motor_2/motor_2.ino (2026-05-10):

#include <Stepper.h>
#include <Servo.h>

// ==========================================
// 1. STEPPER MOTOR CONFIGURATION (PROBE)
// ==========================================
const int stepsPerRevolution = 200;

// Pins for DFRobot L298N Black Edition
const int pinM1 = 4; // Direction Motor 1
const int pinE1 = 5; // Enable Motor 1
const int pinE2 = 6; // Enable Motor 2
const int pinM2 = 7; // Direction Motor 2

// Initialize stepper using only direction pins (M1, M2)
Stepper probeStepper(stepsPerRevolution, pinM1, pinM2);


// ==========================================
// 2. ESC CONFIGURATION (WHEELS)
// ==========================================
const int leftEscPin = 9;
const int rightEscPin = 10;

Servo leftESC;
Servo rightESC;

// ESC Parameters / Boundaries
const int ESC_NEUTRAL = 90;
const int ESC_MIN = 0;
const int ESC_MAX = 180;

// ==========================================
// 3. FAILSAFE & STATE TRACKING
// ==========================================
unsigned long lastCommandTime = 0;
const unsigned long FAILSAFE_TIMEOUT_MS = 1000; // Stops motors if no command in 1000ms
bool isStopped = true;

// Probe State Machine for non-blocking continuous movement
enum ProbeState { PROBE_STOP, PROBE_UP, PROBE_DOWN };
ProbeState currentProbeState = PROBE_STOP;


// ==========================================
// SETUP ROUTINE
// ==========================================
void setup() {
  Serial.begin(9600);
  Serial.setTimeout(10);

  // --- Setup Stepper ---
  pinMode(pinE1, OUTPUT);
  pinMode(pinE2, OUTPUT);
  
  // Keep the Enable pins HIGH so the driver maintains holding torque
  digitalWrite(pinE1, HIGH);
  digitalWrite(pinE2, HIGH);
  
  // Low speed for high torque when digging into the soil
  probeStepper.setSpeed(50); 

  // --- Setup ESCs ---
  leftESC.attach(leftEscPin);
  rightESC.attach(rightEscPin);

  // Send neutral signal to initialize ESCs safely
  stopWheels();

  Serial.println("System Initialized. Awaiting commands from Raspberry Pi.");
}


// ==========================================
// MAIN LOOP: COMMAND PARSER
// ==========================================
void loop() {
  // Check if Raspberry Pi sent a command via USB
  if (Serial.available() > 0) {
    char commandType = Serial.read();

    // Skip trailing whitespace or random characters
    if (commandType == '\n' || commandType == '\r' || commandType == ' ') {
      return;
    }

    lastCommandTime = millis(); // Refresh the failsafe timer
    
    // Command 'S': Fixed steps block (Legacy compatibility)
    if (commandType == 'S') {
      int steps = Serial.parseInt();
      moveProbe(steps);
      currentProbeState = PROBE_STOP;
    }
    
    // Command 'U': Start moving Probe UP continuously
    else if (commandType == 'U') {
      currentProbeState = PROBE_UP;
      Serial.println("Probe -> Moving UP.");
    }
    
    // Command 'D': Start moving Probe DOWN continuously
    else if (commandType == 'D') {
      currentProbeState = PROBE_DOWN;
      Serial.println("Probe -> Moving DOWN.");
    }

    // Command 'F': Forward
    // Physically inverted: now subtracts to go forward
    else if (commandType == 'F') {
      int speed = Serial.parseInt(); 
      moveDirection(-speed, -speed);
      isStopped = false;
    }

    // Command 'B': Backward
    // Physically inverted: now adds to go backward
    else if (commandType == 'B') {
      int speed = Serial.parseInt();
      moveDirection(speed, speed);
      isStopped = false;
    }

    // Command 'L': Left (Skid steer mapping)
    else if (commandType == 'L') {
      int speed = Serial.parseInt();
      moveDirection(speed, -speed);
      isStopped = false;
    }

    // Command 'R': Right (Skid steer mapping)
    else if (commandType == 'R') {
      int speed = Serial.parseInt();
      moveDirection(-speed, speed);
      isStopped = false;
    }

    // Command 'M': Independent Motors Mode [LeftPWM RightPWM]
    // Allows Camera to define absolute differential forces (e.g. Curve without mechanical brake)
    else if (commandType == 'M') {
      int leftPwm = Serial.parseInt();
      int rightPwm = Serial.parseInt();
      driveWheels(leftPwm, rightPwm); 
      isStopped = false;
    }

    // Command 'X': Hard Stop (Stop Everything)
    else if (commandType == 'X') {
      stopWheels();
      currentProbeState = PROBE_STOP;
      Serial.println("SYSTEM HALTED: Wheels and Probe stopped.");
    }
  }

  // --- Failsafe Watchdog Routine ---
  // If the robot hasn't received any command from the Raspberry Pi 
  // within the timeout limit, stop everything safely.
  if (millis() - lastCommandTime > FAILSAFE_TIMEOUT_MS) {
    if (!isStopped || currentProbeState != PROBE_STOP) {
      Serial.println("WARNING: Communication Timeout. Engaging failsafe (All Motors Stopped).");
      stopWheels();
      currentProbeState = PROBE_STOP;
    }
  }

  // --- Probe Continuous Movement Task ---
  // This gives non-blocking step control 
  if (currentProbeState == PROBE_UP) {
    probeStepper.step(1);  // Needs testing for actual physical polarity (Up vs Down)
  } else if (currentProbeState == PROBE_DOWN) {
    probeStepper.step(-1);
  }
}


// ==========================================
// FUNCTIONS
// ==========================================

// Legacy blocking function
void moveProbe(int steps) {
  Serial.print("Moving probe by steps: ");
  Serial.println(steps);
  probeStepper.step(steps);
  Serial.println("Probe movement complete.");
}


// Wrapper to map relative intensities (-90 to +90) to ESC absolute PWM (0 to 180)
void moveDirection(int leftRelative, int rightRelative) {
  int leftPWM = ESC_NEUTRAL + leftRelative;
  int rightPWM = ESC_NEUTRAL + rightRelative;
  driveWheels(leftPWM, rightPWM);
}


// Core function to control the skid-steering wheels robustly
void driveWheels(int leftPWM, int rightPWM) {
  // Always limit values explicitly to prevent hardware glitches (constrain to 0-180)
  leftPWM = constrain(leftPWM, ESC_MIN, ESC_MAX);
  rightPWM = constrain(rightPWM, ESC_MIN, ESC_MAX);
  
  leftESC.write(leftPWM);
  rightESC.write(rightPWM);
  
  Serial.print("Wheels -> L: ");
  Serial.print(leftPWM);
  Serial.print(" R: ");
  Serial.println(rightPWM);
}


// Function to safely stop the vehicle wheels
void stopWheels() {
  leftESC.write(ESC_NEUTRAL); 
  rightESC.write(ESC_NEUTRAL);
  isStopped = true;
}

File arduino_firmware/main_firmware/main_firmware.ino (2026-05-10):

/**
 * AGRI-Scout Firmware v5.0 (Robust Checksum + DC RC-Driver)
 */

#include <Servo.h>
#include <Stepper.h>

// ==========================================
// 1. STEPPER MOTOR CONFIGURATION (PROBE)
// ==========================================
const int STEPS_PER_REVOLUTION = 200;
const int pinM1 = 4; // Direction Motor 1
const int pinE1 = 5; // Enable Motor 1
const int pinE2 = 6; // Enable Motor 2
const int pinM2 = 7; // Direction Motor 2

/// Global variable to track the last direction (add at the top of the code)
char lastMoveCmd = 'X';

Stepper probeStepper(STEPS_PER_REVOLUTION, pinM1, pinM2);

// Probe State Machine
enum ProbeState { PROBE_STOP, PROBE_UP, PROBE_DOWN };
ProbeState currentProbeState = PROBE_STOP;

// ==========================================
// 2. RC DRIVER CONFIGURATION (WHEELS)
// ==========================================
const int PIN_ESC_LEFT = 9;
const int PIN_ESC_RIGHT = 10;

Servo leftESC;
Servo rightESC;

const int ESC_NEUTRAL = 90;
const int ESC_MIN = 0;
const int ESC_MAX = 180;

// ==========================================
// 3. COMMUNICATION & FAILSAFE
// ==========================================
const byte START_BYTE = 0x3C; // '<'
const byte END_BYTE = 0x3E;   // '>'

unsigned long lastCommandTime = 0;
const unsigned long FAILSAFE_TIMEOUT_MS = 1000;
bool isStopped = true;

bool newData = false;
byte receivedCommand = 0;
byte receivedValue = 0;

void setup() {
  Serial.begin(9600);

  // Stepper Setup
  pinMode(pinE1, OUTPUT);
  pinMode(pinE2, OUTPUT);
  digitalWrite(pinE1, HIGH);
  digitalWrite(pinE2, HIGH);
  probeStepper.setSpeed(50);

  // Wheels Setup
  leftESC.attach(PIN_ESC_LEFT);
  rightESC.attach(PIN_ESC_RIGHT);
  stopWheels();

  Serial.println("SYSTEM: Initialized. Robust Protocol Active.");
}

void loop() {
  receiveSecurePacket();

  if (newData) {
    executeCommand((char)receivedCommand, (int)receivedValue);
    newData = false;
  }

  // Watchdog Failsafe
  if (millis() - lastCommandTime > FAILSAFE_TIMEOUT_MS) {
    if (!isStopped || currentProbeState != PROBE_STOP) {
      Serial.println("WARNING: Timeout! Engaging Failsafe.");
      stopWheels();
      currentProbeState = PROBE_STOP;
    }
  }

  // Non-blocking Probe Movement
  if (currentProbeState == PROBE_UP) {
    probeStepper.step(1);
  } else if (currentProbeState == PROBE_DOWN) {
    probeStepper.step(-1);
  }
}

// --- PACKET PARSER ---
void receiveSecurePacket() {
  static boolean recvInProgress = false;
  static byte index = 0;
  byte incomingByte;
  static byte packetBuffer[3];

  while (Serial.available() > 0 && newData == false) {
    incomingByte = Serial.read();

    if (recvInProgress == true) {
      if (incomingByte != END_BYTE) {
        packetBuffer[index] = incomingByte;
        index++;
        if (index >= 3)
          index = 2; // Prevent overflow
      } else {
        recvInProgress = false;
        index = 0;

        byte cmd = packetBuffer[0];
        byte val = packetBuffer[1];
        byte rx_checksum = packetBuffer[2];

        // Verify Integrity
        if ((cmd ^ val) == rx_checksum) {
          receivedCommand = cmd;
          receivedValue = val;
          newData = true;
          lastCommandTime = millis(); // Refresh Watchdog
        }
      }
    } else if (incomingByte == START_BYTE) {
      recvInProgress = true;
    }
  }
}

void executeCommand(char cmd, int speed) {

  // --- THE "AUTO-SPACE" LOGIC ---
  // If the command is a movement, AND it's different from the last one, AND we
  // aren't already stopped
  if ((cmd == 'F' || cmd == 'B' || cmd == 'L' || cmd == 'R') &&
      (cmd != lastMoveCmd && lastMoveCmd != 'X')) {

    Serial.println("SYSTEM: AUTO-SPACE (BRAKE INITIATED)");
    stopWheels(); // Force Neutral (90)

    // Mimic the human delay of pressing the Spacebar
    delay(2 * 500);

    // CRITICAL FIX: Clear the Serial buffer.
    // The Pi kept sending packets while we were waiting 500ms.
    // We must flush them to avoid confusing the ESC with queued commands.
    while (Serial.available() > 0) {
      Serial.read();
    }

    newData = false;
    lastMoveCmd = 'X'; // Reset state to Neutral
  }

  // Update the tracker for the next cycle
  lastMoveCmd = cmd;

  // --- NORMAL COMMAND EXECUTION ---
  switch (cmd) {
  case 'F':
    moveDirection(-speed, -speed);
    Serial.println("MOVING: FWD");
    break;
  case 'B':
    moveDirection(speed, speed);
    Serial.println("MOVING: BACK");
    break;
  case 'L':
    moveDirection(speed, -speed);
    Serial.println("TURNING: LEFT");
    break;
  case 'R':
    moveDirection(-speed, speed);
    Serial.println("TURNING: RIGHT");
    break;
  case 'U':
    currentProbeState = PROBE_UP;
    Serial.println("PROBE: UP");
    break;
  case 'D':
    currentProbeState = PROBE_DOWN;
    Serial.println("PROBE: DOWN");
    break;
  case 'X':
    stopWheels();
    currentProbeState = PROBE_STOP;
    lastMoveCmd = 'X';
    Serial.println("SYSTEM: STOPPED");
    break;
  }
}

// --- WHEEL MATH (Based on User's working model) ---
void moveDirection(int leftRelative, int rightRelative) {
  int leftPWM = constrain(ESC_NEUTRAL + leftRelative, ESC_MIN, ESC_MAX);
  int rightPWM = constrain(ESC_NEUTRAL + rightRelative, ESC_MIN, ESC_MAX);

  leftESC.write(leftPWM);
  rightESC.write(rightPWM);
  isStopped = false;
}

void stopWheels() {
  leftESC.write(ESC_NEUTRAL);
  rightESC.write(ESC_NEUTRAL);
  isStopped = true;
}

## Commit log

2025-12-21 docs: Initial Pi and Arduino Communication Test
2026-01-06 docs: update pc and raspberry communication
2026-01-06 fix: motor movement
2026-03-10 feat: test motor
2026-03-31 add camera and motors tests made in 31/03
2026-05-08 docs: Luiz mechanical and 3D images
    [battery2.2A_supoport.ipt, battery5A_supoport.ipt, bottom_support.ipt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]
